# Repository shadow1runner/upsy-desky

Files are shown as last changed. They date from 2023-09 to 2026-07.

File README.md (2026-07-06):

# Upsy Desky

Just like <https://github.com/tjhorner/upsy-desky>, but with a `DOIT esp32 DevKit v1`, an added temperature sensor and some not-so-beautiful wiring ;-).

* [Upsy Desky](#upsy-desky)
  * [Iterations](#iterations)
  * [Changes to upstream](#changes-to-upstream)
  * [How To...](#how-to)
    * [Set up a development environment?](#set-up-a-development-environment)
    * [Connect to upsy-desky the very first time?](#connect-to-upsy-desky-the-very-first-time)
    * [Change initial settings?](#change-initial-settings)
    * [Perform an upgrade? (e.g., after incorporating upstream changes)](#perform-an-upgrade-eg-after-incorporating-upstream-changes)
  * [Upstream](#upstream)
  * [Wiring](#wiring)
  * [Additional Documentation](#additional-documentation)
  * [Licenses](#licenses)
  * [References](#references)

## Iterations

1. Initially I forked <https://github.com/tjhorner/jarvis-desk> to <https://github.com/shadow1runner/jarvis-desk>; I wired everything as stipulated there, but was not really successful (most likely I had some wires wrong or did some wrong code modifications); anyway, doing more research let to...
2. ... <https://github.com/shadow1runner/FullyJarvis> which in comparison to the former uses one logic shifter less since only the UART connectivity is required; this did work fine, except for the fact that - no matter what I tried changing in code - the screen of the handset never turned off again, and it was the mere fact of not understanding the why which led to
3. ... the current iteration which is, again based on 1. (and what you are reading currently); doing it the second time was way smoother, already having gained more experience didn't hurt either ;-)

## Changes to upstream

This fork has rather small adjustments from the great upstream repo <https://github.com/tjhorner/upsy-desky> (also: cf. commit history):

* I had a `DOIT esp32 DevKit v1` at hand, which also features an `ESP32-WROOM-32` (just as upstream does), but:
  * it has voltage regulators from 5V to 3.3 V already built-in
  * can be powered from 5V (provided by the desk) via its `VIN` pin [1]
* thus, there was no need of having:
  * the `CP2102N` USB/UART adapter
  * the USB-C receptacle
  * 3V3 voltage regulator
* changed the default units to metric units as per SI standard
* changed the GPIO pins based on the PinOut shown below

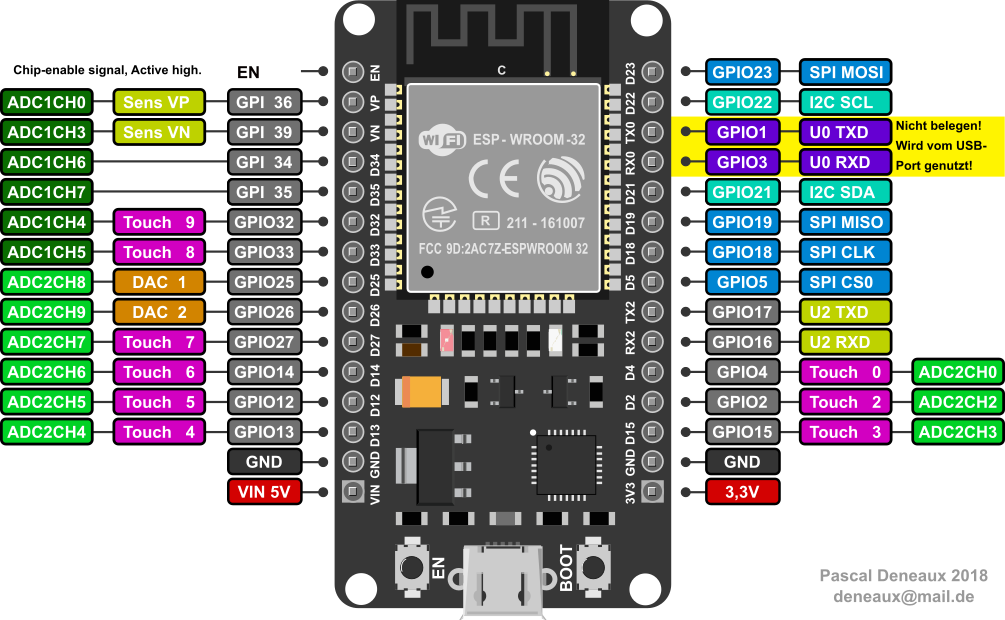
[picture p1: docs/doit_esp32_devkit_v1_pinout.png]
Pinout


In comparison to the upstream pinout:

ESP32 Wroom

| RJ45 Pin [^0] | Color LAN cable | Schematic Name | *Upstream* ESP32 mapped Pin | *New* DOIT esp32 DevKit v1 GPIO Pin | *My* wire color to esp32 | Note |
| --- | --- | --- | --- | --- | --- | --- |
| 1 | orange/white | `DESK_1` | `18` | `GPIO32` | blue | `button_m_pin` |
| 2 | orange | `DESK_2` | `17` | `GPIO16` (`RX2`) | white | UART RX[^1], 5V |
| 3 | green/white | GND | N/A (GND) | N/A (GND) | | |
| 4 | blue | `DESK_4` | `16` | `GPIO17` (`TX2`) | gray | UART TX[^1], 5V |
| 5 | blue/white | +5V | N/A (+5V) | N/A (+5V) | | |
| 6 | green | `DESK_6` | `19` | `GPIO33` | green | `button_bit4_pin` |
| 7 | brown/white | `DESK_7` | `21` | `GPIO25` | yellow | `button_bit1_pin` |
| 8 | brown | `DESK_8` | `22` | `GPIO26` | purple | `button_bit2_pin` |

[^0]
Numbering schema

[^1]
Note: The UART mappings are exchanged in comparison to upstream:

* the original did the swapping during the final mapping to the IC
* this one does it as part of the logic level shifters
* upstream:
  * uart.tx_pin: `16`
  * standing_desk_uart_rx_pin: `17`
* local:
  * standing_desk_uart_tx_pin: `GPIO17`
  * standing_desk_uart_rx_pin: `GPIO16`

Thus:

* `GPIO17` (UART2TX) is mapped to the `DESK_4` (RX) port (upstream: `16` -> `DESK_4`)
* `GPIO16` (UART2RX) is mapped to the `DESK_2` (TX) port (upstream: `17` -> `DESK_2`)

## How To...

Any standing desk that uses RJ45 to connect to the keypad is likely compatible, but the control boxes listed [here](https://upsy-desky.tjhorner.dev/docs/reference/compatibility/) are verified to be compatible.

### Set up a development environment?

* As usual: DON'T try getting it running on Windows, just get a Linux somewhere (e.g., a Raspberry) and you are good to go via running [setup.sh](tools/setup.sh)
* useful commands, after `cd firmware`:
  * `esphome run jarvis_withsecrets.yaml` compiles and flashes the firmware to the board; note that you shortly need to press its `BOOT` button such that the flashing can happen
    > Note: this requires `firmware/secrets.yaml` (not committed to remote), it should look as follows:

      ```yaml
      wifi_ssid: TODO1
      wifi_password: TODO2

      web_user: TODO3
      web_password: TODO4

      ota_password: TODO5
      ```
  * `esphome run debug.yaml` in case you need more information
  * `esphome logs debug.yaml` for connecting to `LOGGER` (UART0)

### Connect to upsy-desky the very first time?

* `fully-jarvis` is configured to auto-reconnect to known WiFi networks; in case this fails, it goes into AP mode and spawns a network named `fully-jarvis`
* connect to said WiFi, using the initial password `Einstieg00`
* once there, it asks you to join a "real" WiFi, simply select one from the list and enter the password
* `fully-jarvis` will reboot and (try to) connect to known WiFi networks

### Change initial settings?

* after connecting to a known WiFi network (cf. [Connect to upsy-desky the very first time?](#connect-to-upsy-desky-the-very-first-time)), you should be able to connect via <http://fully-jarvis.local/>
* otherwise check your home network for a the IP address of a device named `fully-jarvis`
* there you can change settings (like units etc.)
* make sure to press the `Upsy Desky Restart` button once done such that the settings are persisted in flash and take effect

### Perform an upgrade? (e.g., after incorporating upstream changes)

* Rebase and push changes to `origin`
  > Note: `pip install --upgrade esphome` might be worthwhile in case you haven't fiddled with esphome for a while
* now either:
  * On gitHub:
    * [start a new release](https://docs.github.com/en/repositories/releasing-projects-on-github/managing-releases-in-a-repository) which will cause the CI pipeline to create a new firmware
    * download the release binaries, the `firmware.bin` is the file you need
    * navigate to your upsy-desky via a browser and upload said binaries which will perform an OTA upgrade
  * On your local development environment:
    * run `esphome run jarvis_withsecrets.yaml`, which compiles and flashes the firmware to the board; note that you shortly need to press its `BOOT` button such that the flashing can happen

## Upstream

* For any further information see upstream <https://github.com/tjhorner/upsy-desky/>

## Wiring

Cf. `pcb` folder

> Note: 44e848bba46ff77500eab2dd5d7e8c4475432bc6 and 44b5dc0cdc3e29ba02147292698e92e65c89b479 tried to mitigate connectivity issues when the board, after boot, just didn't want to connect to Wifi; these did not help though (and have thus been reverted); what brought long-term remedy was connecting the USB board via USB (powered by one of the monitors), then enough stable voltage (?) lead to a clean boot.

## Additional Documentation

You can find everything you need in the [GitHub wiki](https://github.com/tjhorner/upsy-desky/wiki/Getting-Started).

## Licenses

The ESPHome configs are licensed under MIT; everything else (enclosure and PCB design) are CC BY-NC-SA 4.0. The appropriate license files are available in the root of the repo.

## References

[1] PinOut and schematics of DOIT ESP32 Devkit V1: <https://github.com/SmartArduino/SZDOITWiKi/wiki/ESP8266---ESP32>

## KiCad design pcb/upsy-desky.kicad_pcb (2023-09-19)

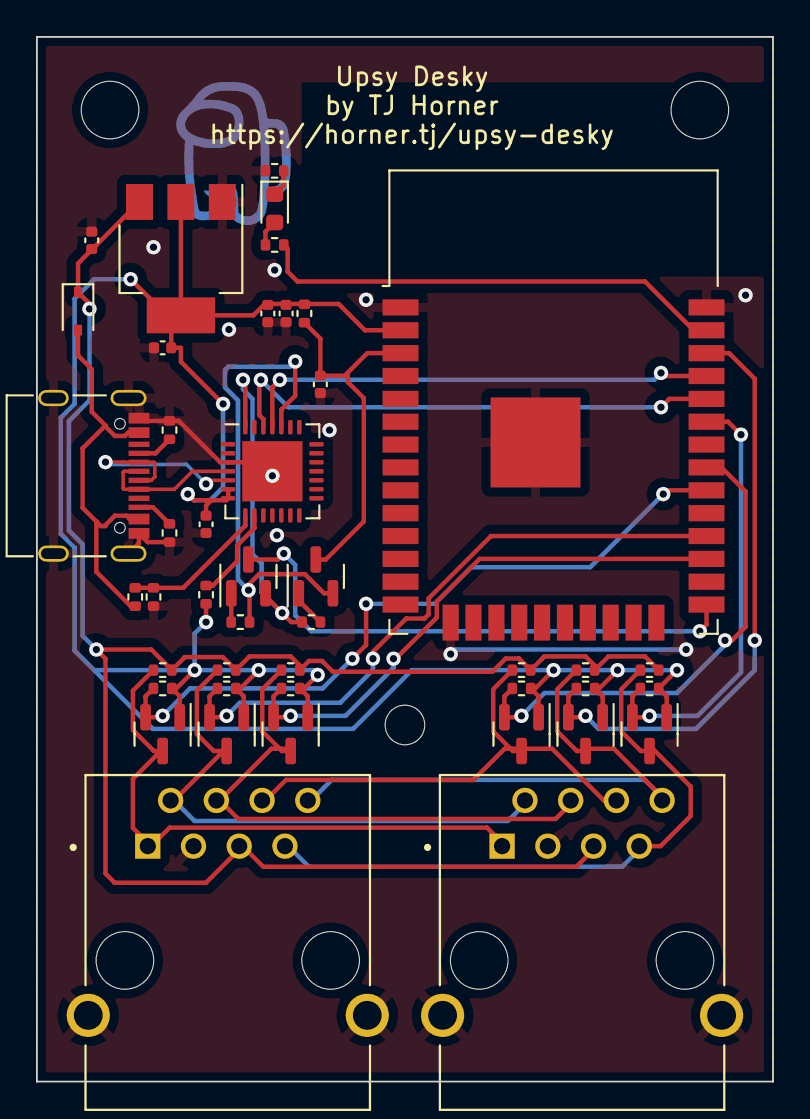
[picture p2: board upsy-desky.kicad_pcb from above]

Board: 2 copper layers, 40.9 x 58.0 mm, 45 parts (0 on the bottom side), 33 nets.

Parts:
C1, C2, C5, C6: 10u; C_0402_1005Metric
C3: 1u; C_0402_1005Metric
C4: 0.1u; C_0402_1005Metric
D1: 1N5817; D_SOD-323
D2: LED; LED_0603_1608Metric
J1, J2: RJ45; ASSMANN_A-2004-2-4-LPS-N-R
J3: USB_C_ReceptacleUSB2.0; USB_C_Receptacle_Palconn_UTC16-G
Q1, Q2: MMBT3904; SOT-23
Q3, Q4, Q5, Q6, Q7, Q8: BSS138; SOT-23
R1, R2: 5.1k; R_0402_1005Metric
R3, R4, R5, R6, R7, R8, R9, R10, R11, R12, R13, R14, R15, R16, R17: 10k; R_0402_1005Metric
R18: 1k; R_0402_1005Metric
R19: 22.1k; R_0402_1005Metric
R20: 47.5k; R_0402_1005Metric
R21: 470; R_0402_1005Metric
R22: 940; R_0402_1005Metric
Ref**: Val**; amongy
U1: CP2102N-Axx-xQFN28; QFN-28-1EP_5x5mm_P0.5mm_EP3.35x3.35mm
U2: AMS1117-3.3; SOT-223-3_TabPin2
U3: ESP32-WROOM-32

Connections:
+3V3: C2.1, C4.1, C5.1, C6.1, Q3.1 (G), Q4.1 (G), Q5.1 (G), Q6.1 (G), Q7.1 (G), Q8.1 (G), R5.1, R6.2, R7.2, R10.2, R11.2, R14.2, R16.2, R18.1, U1.6 (VDD), U1.7 (VREGIN), U2.2 (VO), U3.2 (VDD)
+5V: C1.1, D1.1 (K), J1.5, J2.5, R8.2, R9.2, R12.2, R13.2, R15.2, R17.2, U2.3 (VI)
/DESK_1: J1.1, J2.1, Q3.3 (D), R8.1
/DESK_2: J1.2, J2.2, Q5.3 (D), R12.1
/DESK_4: J1.4, J2.4, Q4.3 (D), R9.1
/DESK_6: J1.6, J2.6, Q6.3 (D), R13.1
/DESK_7: J1.7, J2.7, Q7.3 (D), R15.1
/DESK_8: J1.8, J2.8, Q8.3 (D), R17.1
/DTR: Q1.2 (E), R4.1, U1.28 (~DTR)
/EN: C3.1, Q2.3 (C), R5.2, U3.3 (EN)
/ESP_RX: U1.26 (TXD), U3.34 (RXD0/IO3)
/ESP_TX: U1.25 (RXD), U3.35 (TXD0/IO1)
/GPIO0: Q1.3 (C), U3.25 (IO0)
/GPIO16: Q4.2 (S), R7.1, U3.27 (IO16)
/GPIO17: Q5.2 (S), R10.1, U3.28 (IO17)
/GPIO18: Q3.2 (S), R6.1, U3.30 (IO18)
/GPIO19: Q6.2 (S), R11.1, U3.31 (IO19)
/GPIO21: Q7.2 (S), R14.1, U3.33 (IO21)
/GPIO22: Q8.2 (S), R16.1, U3.36 (IO22)
/GPIO23: R21.1, U3.37 (IO23)
/RTS: Q2.2 (E), R3.1, U1.24 (~RTS)
/USB_CC1: J3.A5 (CC1), R2.2
/USB_CC2: J3.B5 (CC2), R1.2
/USB_D+: J3.A6 (D+), J3.B6 (D+), U1.4 (D+)
/USB_D-: J3.A7 (D-), J3.B7 (D-), U1.5 (D-)
GND: C1.2, C2.2, C3.2, C4.2, C5.2, C6.2, J1.3, J1.S1 (SHIELD), J1.S2 (SHIELD__1), J2.3, J2.S1 (SHIELD), J2.S2 (SHIELD__1), J3.A1 (GND), J3.A12 (GND), J3.B1 (GND), J3.B12 (GND), J3.S1 (SHIELD), R1.1, R2.1, R20.2, R22.2, U1.3 (GND), U1.29 (GND), U2.1 (GND), U3.1 (GND), U3.15 (GND), U3.38 (GND), U3.39 (GND)
unnamed: D2.1 (K), R22.1
unnamed: D2.2 (A), R21.2
unnamed: Q1.1 (B), R3.2
unnamed: Q2.1 (B), R4.2
unnamed: R18.2, U1.9 (~RST)
unnamed: R19.2, R20.1, U1.8 (VBUS)
VBUS: D1.2 (A), J3.A4 (VBUS), J3.A9 (VBUS), J3.B4 (VBUS), J3.B9 (VBUS), R19.1

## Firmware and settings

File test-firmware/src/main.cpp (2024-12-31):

#include <Arduino.h>

#define LED_BUILTIN 23

// These correspond to RJ45 pins 1-6
int pins_to_test[] = {
  18,
  17,
  16,
  19,
  21,
  22
};

void setup() {
  Serial.begin(9600);

  pinMode(LED_BUILTIN, OUTPUT);
  
#ifdef TEST_HOST
  Serial.println("Initializing test host...");

  for (int &pin : pins_to_test) {
    pinMode(pin, INPUT);
  }

  digitalWrite(LED_BUILTIN, HIGH);

  delay(200);

  for (int &pin : pins_to_test) {
    Serial.print("Waiting for pin ");
    Serial.print(pin);
    Serial.println();

    while (digitalRead(pin) == LOW) {
      delay(50);
    }

    digitalWrite(LED_BUILTIN, LOW);
    delay(100);
    digitalWrite(LED_BUILTIN, HIGH);
  }

  digitalWrite(LED_BUILTIN, LOW);
#else
  digitalWrite(LED_BUILTIN, HIGH);

  Serial.println("Initializing test target...");

  for (int &pin : pins_to_test) {
    pinMode(pin, OUTPUT);
    digitalWrite(pin, LOW);
  }
#endif
}

void loop() {
#ifdef TEST_TARGET
  for (int &pin : pins_to_test) {
    Serial.print("Pulsing pin ");
    Serial.print(pin);
    Serial.println();

    digitalWrite(pin, HIGH);
    delay(300);
    digitalWrite(pin, LOW);
  }
#endif
}

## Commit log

2023-03-26 Firmware: Adapt pinout to `esp32doit-devkit-v1` - working fine
2023-03-26 PCB: Change schematics to esp32 devkit
    [upsy-desky.kicad_pcb, upsy-desky.kicad_sch]
2023-10-29 (Try to) minimize wifi connectivity issues
    As it happens, the ESP32 device sometimes just doesn't want to connect to Wifi; if it doesn't happen from after
    booting it's usually never able to connect; even hard rebooting it doesn't help;
    given all this, it's hard to troubleshoot, even though one could try to store log entries to flash for later
    analysis.
    https://esphome.io/components/wifi.html#wifi-power-save-mode which on an ESP32 is by default set to `LIGHT` has been disabled, maybe this helps
2023-10-30 Disable temperature sensor alltogether
    My current suspicion: the esp32 needs more current to boot properly, because as soon as you connect an external power supply (be it a power bank or a raspberry pi) it connects to WiFi immediatelly w/o any issues
2023-10-31 Revert "Disable temperature sensor alltogether"
    This reverts commit 76f00e81c7fbb3a47277f1d83f3722821183d30a.
2023-10-31 Docs: add external power source for clean boots
2024-12-31 Try to reduce power consumption
2026-11-08 CI: pick up the firmware from ESPHome 2026.10's ESP-IDF build directory
    ESPHome 2026.10 builds ESP32 with ESP-IDF directly instead of PlatformIO,
    so the images are in .esphome/build/<name>/build/ (firmware.factory.bin,
    firmware.ota.bin) instead of .pioenvs/<name>/. Artifact names unchanged.
